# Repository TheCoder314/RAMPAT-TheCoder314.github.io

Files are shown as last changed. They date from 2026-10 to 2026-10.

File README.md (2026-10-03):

# R.A.M.P.A.T.

**Rapid, Affordable, Modular, Printed, Aerial Tiltrotor** — an open-source, 3D-printed tiltrotor VTOL for emergency response, by Aarit Dixit.

Website: `https://thecoder314.github.io/RAMPAT-TheCoder314.github.io/`

## Downloads

| File | Contents |
| --- | --- |
| `files/RAMPAT-all-files.zip` | Everything: STEP, STLs, PCB Gerbers, poster |
| `files/cad/RAMPAT-CAD-assembly-STEP.zip` | Full assembly for modification |
| `files/cad/RAMPAT-printable-STL.zip` | 53 printable parts + parts list |
| `files/pcb/RAMPAT-PCB.zip` | Flight controller Gerbers, upload directly to a fab |

## Printing (LW-PETG, gyroid infill)

| Parts | Walls | Infill |
| --- | --- | --- |
| Fuselage shells | 1 | 3% |
| Wings | 1 | 5% |
| Connectors | 3 | 20% |
| Everything else | 2 | 20% |

## Repo layout

```
index.html              the website
assets/                 images and part thumbnails
files/                  everything visitors download
source/cad/             full STEP assembly + parts-list.csv
source/pcb/             Gerber + drill files from KiCad
tools/build_zips.py     rebuilds every ZIP in files/
```

After changing anything in `source/` or `files/cad/stl/`, run `python3 tools/build_zips.py`.

## Publish on GitHub Pages

1. Push this folder to a GitHub repository.
2. Settings → Pages → Deploy from a branch → `main`, `/ (root)`.

## License

[CC BY-NC 4.0](https://creativecommons.org/licenses/by-nc/4.0/). See `LICENSE.txt`.

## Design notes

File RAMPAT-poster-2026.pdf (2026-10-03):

Year 2: Development of R.A.M.P.A.T.

# (Rapid, Affordable, Modular, Printed, Aerial Tiltrotor) For Emergency Response

# Aarit Dixit

INTRODUCTION | METHODS | STATISTICAL ANALYSIS

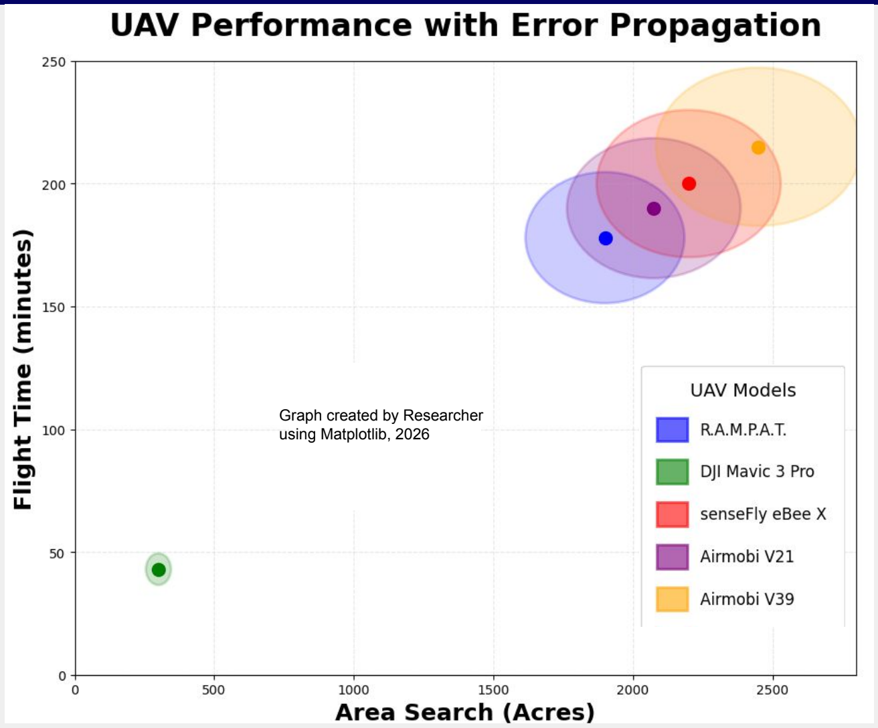
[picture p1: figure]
Graph created by Researcher using Matplotlib, 2026

# CONCLUSIONS

# FUTURE WORK

- First 3D‑printed tiltrotor VTOL for disaster relief delivers $10k‑class endurance and search performance for under $1k, including thermal imaging for full day/night missions.
- Fully modular, 3D‑printed airframe enables fast, low‑cost field repairs and upgrades, turning crashes into quick recoveries and boosting mission flexibility.
- Engineered for resilience with <1% failure risk, trading minor impact‑resistance limits for unmatched maintainability and continuous deployment for fire departments, NGOs, and community teams.

Overall, the engineering design criteria were met based on flight data, validating R.A.M.P.A.T.’s potential as a viable solution for global first responders.

## Unmanned Aerial Vehicles (UAV)

# RESULTS

Fig 1. Airflow Property Fields of R.A.M.P.A.T. Geometry | Fig 2. CFD-Calculated Forces
Low | High

Hovering advantage
Endurance disadvantage

Images of CFD fields, highlighting optimal aerodynamics and airflow separation.

Utility of multirotor,
efficiency of fixed-wing
Expensive (>$12,000)
Extra Weight
Multirotor | Fixed-Wing | VTOL

# DISCUSSION

CFD forces show convergence, highlighting a valid simulation.
Chart created by Researcher using Google Sheets, 2026

Modeling: Using manufacturer data, assorted industry UAVs were compared to R.A.M.P.A.T., with the company-reported data ranges being used for analysis.
Overlap Interpretation: Overlap of uncertainty envelopes indicates plausible performance similarity, while non-overlap suggests likely separation.
Comparative Inference: Within uncertainty bounds, R.A.M.P.A.T. overlaps with mid-tier platforms (~$8-12k) at a cost of less than $1000 and demonstrates clear separation from lower-cost alternatives (4-6x better), showing dominance in cost-constrained regimes.

Graph displays the overlap in area search capability and flight time shown by R.A.M.P.A.T. and industry-level drones, showcasing similar performance at a fraction of the cost.

Wing
Wing split in 6 parts and slotted together with a carbon-fiber tube for rigidity. Uses a NACA 6409 airfoil for high lift and control authority.

Fuselage
Three-part fuselage stores avionics and payload, including battery, PCB, and thermal camera.

Tilt Mechanism
To efficiently switch between flight modes, a tilt mechanism changes the motor angle
based on flight mode.

V-Tail
To reduce drag compared to T-tails, a V-tail combines the pitch and yaw axes in
differential movement.

Cruise/Endurance efficiency Limited take-off versatility

Flight Testing Procedure

Preflight
- Install battery, power avionics, verify telemetry, control surfaces
- Arm system; confirm hover, transition, and fixed-wing modes

Hover Test
- Vertical takeoff in hover
- Hold altitude for 5 minutes, log current draw and
gyroscope data

Fixed-Wing Cruise
- Switch to fixed-wing mode
- Cruise for 10 minutes to log gyroscope, airspeed, and
power use data

Recovery
- Transition back to hover
- Controlled vertical landing
- Disarm and power down
avionics
- Repeat 15 times

Transition Test
- Climb to 50 ft AGL
- Enter transition mode
- Hold fixed throttle for 2 minutes, log gyroscope and airspeed data
- Locate survivors & assess damage to aid first responders in rescue missions
- Able to operate in hostile environments unsuitable for humans.
- Deliver critical supplies to stranded victims ahead of ground teams
- Extremely expensive (>$10,000), keeping them out of reach for over 80% of global first-responder agencies
Background | ➢ In the past decade, over 400,000 lives
| were lost to natural disasters, most of which happened in developing countries. ➢ Of these, a projected 75% of casualties happened in the 48 hours after the event, during which first responders were critical for analyzing damage and rescue missions. ➢ In the aftermath, aerial reconnaissance is crucial for aiding first responders.

An Unmanned Aerial Vehicle (UAV) is any vehicle that doesn’t have a pilot on board and is either remotely piloted or autonomous.

Flight tests come close to the CFD-calculated “maximum” flight time.

Get IMU
Data

Fuse IMU
Data

Get
Desired
Position

PID Control

Control
Mixing

Actuator
Outputs

Vehicle
Response

Design: Low-cost VTOL using foam and cardboard.
Lesson: Fragile, could not achieve stable flight. Required a complete design overhaul. Important as it established a proof-of-concept.

Design Change: Modular,
3D-printed parts.
Problems: Misaligned CoG,
high aerodynamic drag, and structural instability from wooden spars.
Lesson: Core concept was
viable, but the airframe
structure and aerodynamics needed complete revision for flight.
Iteration 1 | Iteration 2 | Iteration 3

Design Changes:
Replaced wooden
spars/booms with carbon fiber for strength, weight, and
correct CoG.
Improved aerodynamics using CFD data and a V-tail design. Implemented a part-slotting system.
Outcome: Achieved structural stability and flight performance.

Aftermath of Hurricane Melissa in Jamaica, 2025. Floods destroyed the country’s ground infrastructure, leading to survivor searching efforts taking nearly two months.
Source: https://supportjamaica.gov.jm/

R.A.M.P.A.T. surpasses its cost category while being comparable to $10,000 systems in the key metrics of endurance and search capability.

UAV in a California forest fire, 2024 Source: www.fire.ca.gov

Due to unique design and cost constraints, a custom flight controller PCB was developed (diagram to the left).

Key features:
- 85% cost reduction ($75 vs. $500+)
- Full sensor integration
- Long-range radio telemetry
- High-frequency flight
stabilization
- Off-the-shelf sensors with custom control software

Flight control loop, controlling stabilization and movement.

R.A.M.P.A.T. has an order-of-magnitude advantage in the metrics of Flight Time Per Dollar and Search Area Per Dollar (Based on retail price of UAVs/material cost of R.A.M.P.A.T, as electrical cost is negligible when environmental factors are taken to consideration)

DJI Mavic, Image from DJI, 2023
https://www.djiusa.com/products/dji-mavic.

SenseFly eBeeX, Image from SenseFly, 2024
https://eaglenxt.com/drones/ebee-x/

Airmobi V21, Image from Airmobi, 2026
https://www.airmobi.com/product/airmobi-v21/
Pressure, 15 m/s | Velocity, 15 m/s
Pressure, 17.5 m/s | Velocity, 17.5 m/s
Pressure, 20 m/s | Velocity, 20 m/s
Pressure, 22.5 m/s | Velocity, 22.5 m/s
Flight Controller | Computational Fluid Dynamics

Full view of PCB, showing signal routes and components.

73% drag
reduction
Geometry 1 | Geometry 7

Geometric Optimization:
- Reducing high-pressure (red) areas.
- Increasing low-pressure (blue) areas on top of the wing.
- These two factors increase Lift/Drag ratio.

Final Results:
- L/D ratio of 12.1 (industry is 10+).
- High lift at lower speeds, increasing payload capacity.
- Streamlined fuselage + Landing gear.

Photo taken by Researcher, 2024

Image created by
Researcher using
Onshape, 2025

Image created by
Researcher using Onshape, 2025

Image created by Researcher using Onshape, 2025

Chart created by Researcher using Google Sheets, 2026

Image created by
Researcher using
SimScale, 2025

Image created by
Researcher using
SimScale, 2025

Image created by
Researcher using
SimScale, 2025

Image created by
Researcher using
SimScale, 2025

Image created by
Researcher using
SimScale, 2025

Image created by
Researcher using
SimScale, 2025

Image created by
Researcher using
SimScale, 2025

Image created by
Researcher using
SimScale, 2025

Image created by Researcher using SimScale, 2025

Image created by Researcher using SimScale, 2025

Diagram created by Researcher using Google Drawing, 2025

Image created by Researcher using KiCad, 2025

Diagram created by Researcher using Google Drawing, 2026

Proportion-Integral-Derivative Equation Transition Control Mixing Equation

where:
- δ is the true control surface output.
- δcmd is the pilot-given control surface output.
- V represents the measured velocity

# RESEARCH OBJECTIVES

Engineering Problem
Current UAVs are not sufficiently accessible to global first responder groups due to a lack of balance between performance and monetary cost.
Research Question
Can we develop a cost-efficient UAV that balances performance and cost to be an effective tool for first responders?

## Engineering Design Criteria

Performance:
>1800 acre search
capability, >2.75
hour endurance

Affordability:
Contain a materials
cost of <$1000

Functionality:
Swappable parts,
VTOL capability

Brainstorming R.A.M.P.A.T.

### 3D Printed Manufacturing

### Tiltrotor Propulsion

### Modular Design

Hover | Transition | Cruise
- Traditional VTOLs use redundant propulsion systems for hover and cruise.
- Tiltrotor VTOLs combine hover and cruise in the same propulsion system, reducing cost.
- While developed, tiltrotor VTOLs are rarely used in first response and have never been implemented in a 3D-printed first response aircraft.
- Parts slot together, allowing for repairs and upgrades.
- Combined with 3D printing, this allows R.A.M.P.A.T. to be easily repaired.
- Total assembly time (including manufacturing+part sourcing) <48 hours, 5x less than industry UAVs.
CAD Model | 3D Print
- PETG (Polyethylene Terephthalate Glycol-modified) enables rapid, low-cost airframe production
- Allows lightweight, strong structures to maximize flight endurance for long-range search.
- UV-resistant & waterproof

Photo taken by Researcher, 2025 Image created by Researcher using Onshape, 2025

Image created by Researcher using Onshape, 2025

Image created by Researcher using Onshape, 2025

Image created by
Researcher using
Onshape, 2025

Image created by
Researcher using
Onshape, 2025

Image created
by Researcher
using Onshape,
2025

## Aerodynamic Modeling & Validation

- CFD solutions converged across all flight regimes, confirming stable, physically valid aerodynamics.
- Lift, drag, and power predictions aligned closely with flight‑test data.
- Cruise endurance measurements fell within CFD‑predicted bounds, validating the modeling approach.

## Performance Comparison

- Commercial UAV benchmarks used manufacturer‑reported ranges due to lack of variance data.
- R.A.M.P.A.T. variance derived from repeated testing, producing tighter uncertainty (12%).
- Performance judged by overlap of uncertainty envelopes, not single values.
- R.A.M.P.A.T. overlaps mid‑tier ($8k–$12k) UAVs in endurance and search capability; clearly outperforms low‑cost multirotors.

## Cost-Normalized Performance

- Delivers order‑of‑magnitude gains in flight time per dollar and search area per dollar.
- Advantages stem from modular 3D‑printed structure, shared hover/cruise propulsion, and low‑cost custom controller.

## System Design and Operational Impact

- Additive manufacturing introduces minor structural tradeoffs but maintains low failure risk (<1%).
- Modular components enable rapid field repairs.
- Establishes a new cost‑performance benchmark for emergency‑response UAVs.
- Expands access for the 80%+ of first‑responder agencies lacking aerial support.

# ETSD011

Mesh Independence Study | Residual Convergence

where:
- u(t) is the actuator output command.
- e(t) is the error.
- Kp, Ki, and Kd are the proportion, integral, and derivative coefficients.

Chart created by Researcher using Google Sheets, 2026

Chart created by Researcher using Google Sheets, 2026

Equation created by Researcher using Overleaf, 2025 | Equation created by Researcher using Overleaf, 2025

Image created by
Researcher using
SimScale, 2025

### Fig 5. R.A.M.P.A.T. Flight Endurance Compared with CFD-calculated

### Flight Time

Chart created by Researcher using Google Sheets, 2026

UAV | Cost-Based Flight Time (Minutes) | Optimal Area Search (Acres) | Cost (USD)
R.A.M.P.A.T. | 178 | 1900 | $978
DJI Mavic 3 Pro | 43 | 300 | $2,500
senseFly eBeeX | 200 | 2200 | $10,000
Airmobi V21 | 190 | 2075 | $10,000
Airmobi V39 | 215 | 2450 | $11,000

Example swarm network, with 6 R.A.M.P.A.T. UAVs connected with each other to scan an area efficiently.

- Real-World Mission Capability
- Advancing System Autonomy
- Increasing Deployment
Scalability
- Further Environmental and Operational Testing

Sample Data Set

microSD Data
Storage

Plotted Cubic Regression

### Fig 3. Data Extraction Process Fig 4. Industry Comparison Table

Photo taken by Researcher, 2025

Image created by Researcher using Google Sheets, 2025

Image created by Researcher using Matplotlib, 2025

Table created by Researcher using Google Sheets, 2026

### Fig 6. R.A.M.P.A.T. Performance vs Industry

### Fig 7. Cost-Normalized Performance of R.A.M.P.A.T. vs Existing UAVs

Chart created by Researcher using Google Sheets, 2026

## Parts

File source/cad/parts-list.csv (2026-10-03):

group | file | description | print_profile | onshape_name | bounding_box_mm | solid_volume_cm3 | qty
fuselage | fuselage/fuselage-center.stl | Center section, wing joint | Fuselage: 1 wall, 3% gyroid | Part 27 | 250 x 150 x 94 | 601.5 | 1
wing | wing/boom-mount-L.stl | Left boom mount, under wing | Connector: 3 walls, 20% gyroid | Part 40 | 42 x 34 x 16 | 11.0 | 1
tail | tail/v-tail-L.stl | Left V-tail surface | Standard: 2 walls, 20% gyroid | Part 85 | 188 x 134 x 71 | 99.6 | 1
wing | wing/aileron-R2.stl | Right control surface, middle | Wing: 1 wall, 5% gyroid | Part 95 | 210 x 50 x 20 | 36.2 | 1
wing | wing/aileron-R3.stl | Right control surface, outboard | Wing: 1 wall, 5% gyroid | Part 94 | 236 x 50 x 20 | 41.3 | 1
wing | wing/wing-root-plate-L.stl | Left wing root plate | Connector: 3 walls, 20% gyroid | Part 30 | 152 x 45 x 5 | 31.9 | 1
wing | wing/wing-panel-R3.stl | Right wing panel | Wing: 1 wall, 5% gyroid | Part 68 | 250 x 114 x 23 | 317.6 | 1
fuselage | fuselage/fuselage-insert.stl | Internal fuselage insert | Standard: 2 walls, 20% gyroid | Part 1 | 134 x 44 x 29 | 169.4 | 1
tail | tail/v-tail-tip-L.stl | Left V-tail tip | Standard: 2 walls, 20% gyroid | Part 86 | 100 x 57 x 44 | 15.0 | 1
tail | tail/ventral-fin.stl | Ventral fin and rear landing leg | Standard: 2 walls, 20% gyroid | Part 47 | 233 x 211 x 38 | 319.7 | 1
wing | wing/wing-panel-L4.stl | Left wing panel, tip | Wing: 1 wall, 5% gyroid | Part 36 | 259 x 170 x 61 | 461.0 | 1
tail | tail/ruddervator-R.stl | Right ruddervator | Standard: 2 walls, 20% gyroid | Part 92 | 149 x 107 x 31 | 16.1 | 1
wing | wing/wing-panel-R1.stl | Right wing panel, root | Wing: 1 wall, 5% gyroid | Part 61 | 252 x 151 x 31 | 359.9 | 1
nacelles | nacelles/boom-fairing-R.stl | Right boom fairing | Standard: 2 walls, 20% gyroid | Part 60 | 157 x 56 x 37 | 83.7 | 1
nacelles | nacelles/servo-frame-L.stl | Left tilt-servo frame | Standard: 2 walls, 20% gyroid | Part 50 | 56 x 29 x 4 | 2.5 | 1
tail | tail/pin-a.stl | Small pin | Connector: 3 walls, 20% gyroid | Part 3 | 6 x 5 x 5 | 0.1 | 1
nacelles | nacelles/tilt-bracket-R-b.stl | Right tilt bracket, servo side | Standard: 2 walls, 20% gyroid | Part 65 | 73 x 45 x 41 | 26.3 | 1
nacelles | nacelles/front-boom-R.stl | Right motor boom with landing leg | Standard: 2 walls, 20% gyroid | Part 66 | 235 x 235 x 44 | 204.3 | 1
wing | wing/aileron-L3.stl | Left control surface, outboard | Wing: 1 wall, 5% gyroid | Part 97 | 236 x 50 x 20 | 41.3 | 1
nacelles | nacelles/servo-frame-R.stl | Right tilt-servo frame | Standard: 2 walls, 20% gyroid | Part 63 | 56 x 29 x 4 | 2.5 | 1
wing | wing/aileron-L1.stl | Left control surface, inboard | Wing: 1 wall, 5% gyroid | Part 96 | 200 x 50 x 20 | 35.8 | 1
nacelles | nacelles/tilt-bracket-R-a.stl | Right tilt bracket | Standard: 2 walls, 20% gyroid | Part 64 | 73 x 45 x 29 | 22.6 | 1
fuselage | fuselage/fuselage-front.stl | Front fuselage section | Fuselage: 1 wall, 3% gyroid | Part 29 | 250 x 150 x 69 | 539.3 | 1
nacelles | nacelles/front-boom-L.stl | Left motor boom with landing leg | Standard: 2 walls, 20% gyroid | Part 71 | 235 x 207 x 35 | 175.8 | 1
nacelles | nacelles/servo-housing-L.stl | Left tilt-servo housing | Standard: 2 walls, 20% gyroid | Part 72 | 56 x 37 x 29 | 33.8 | 1
wing | wing/wing-panel-R4.stl | Right wing panel, tip | Wing: 1 wall, 5% gyroid | Part 59 | 259 x 170 x 61 | 461.0 | 1
tail | tail/tail-mount.stl | Tail mount and rear motor pod | Standard: 2 walls, 20% gyroid | Part 87 | 212 x 93 x 71 | 300.4 | 1
wing | wing/wing-panel-L1.stl | Left wing panel, root | Wing: 1 wall, 5% gyroid | Part 38 | 252 x 151 x 31 | 359.9 | 1
fuselage | fuselage/nose-cone.stl | Streamlined nose cone | Fuselage: 1 wall, 3% gyroid | Part 69 | 178 x 75 x 69 | 411.2 | 1
tail | tail/tail-boom-sleeve-2.stl | Tail boom sleeve, middle | Standard: 2 walls, 20% gyroid | Part 81 | 243 x 38 x 38 | 162.4 | 1
wing | wing/wing-panel-L2.stl | Left wing panel | Wing: 1 wall, 5% gyroid | Part 53 | 155 x 114 x 23 | 180.5 | 1
nacelles | nacelles/tilt-bracket-L-a.stl | Left tilt bracket | Standard: 2 walls, 20% gyroid | Part 51 | 73 x 45 x 29 | 22.6 | 1
wing | wing/aileron-L2.stl | Left control surface, middle | Wing: 1 wall, 5% gyroid | Part 98 | 210 x 50 x 20 | 36.2 | 1
tail | tail/tail-boom-sleeve-3.stl | Tail boom sleeve, rear | Standard: 2 walls, 20% gyroid | Part 82 | 257 x 38 x 38 | 173.8 | 1
wing | wing/wing-panel-R2.stl | Right wing panel | Wing: 1 wall, 5% gyroid | Part 67 | 155 x 114 x 23 | 180.5 | 1
tail | tail/tail-boom-sleeve-1.stl | Tail boom sleeve, front | Standard: 2 walls, 20% gyroid | Part 41 | 233 x 38 x 38 | 147.1 | 1
nacelles | nacelles/tilt-bracket-L-b.stl | Left tilt bracket, servo side | Standard: 2 walls, 20% gyroid | Part 52 | 73 x 45 x 41 | 26.3 | 1
wing | wing/aileron-R1.stl | Right control surface, inboard | Wing: 1 wall, 5% gyroid | Part 93 | 200 x 50 x 20 | 35.8 | 1
fuselage | fuselage/avionics-tray.stl | Floor plate for PCB and battery | Standard: 2 walls, 20% gyroid | Part 70 | 177 x 139 x 3 | 40.4 | 1
tail | tail/v-tail-R.stl | Right V-tail surface | Standard: 2 walls, 20% gyroid | Part 89 | 188 x 134 x 70 | 99.6 | 1
tail | tail/v-tail-tip-R.stl | Right V-tail tip | Standard: 2 walls, 20% gyroid | Part 90 | 100 x 57 x 44 | 15.0 | 1
tail | tail/control-horn-b.stl | Ruddervator control horn | Standard: 2 walls, 20% gyroid | Part 84 | 20 x 7 x 7 | 0.5 | 1
nacelles | nacelles/boom-fairing-L.stl | Left boom fairing | Standard: 2 walls, 20% gyroid | Part 37 | 157 x 56 x 37 | 83.7 | 1
tail | tail/pin-b.stl | Small pin | Connector: 3 walls, 20% gyroid | Part 4 | 6 x 5 x 5 | 0.1 | 1
tail | tail/ruddervator-L.stl | Left ruddervator | Standard: 2 walls, 20% gyroid | Part 91 | 149 x 107 x 31 | 16.1 | 1
tail | tail/control-horn-a.stl | Ruddervator control horn | Standard: 2 walls, 20% gyroid | Part 83 | 10 x 7 x 6 | 0.2 | 1
fuselage | fuselage/tail-boom-joiner.stl | Joins tail boom to center section | Connector: 3 walls, 20% gyroid | Part 88 | 65 x 27 x 27 | 37.2 | 1
wing | wing/wing-root-plate-R.stl | Right wing root plate | Connector: 3 walls, 20% gyroid | Part 31 | 152 x 45 x 5 | 32.0 | 1
tail | tail/rear-tilt-bracket-b.stl | Rear motor tilt bracket, servo side | Standard: 2 walls, 20% gyroid | Part 80 | 73 x 45 x 41 | 26.3 | 1
tail | tail/rear-tilt-bracket-a.stl | Rear motor tilt bracket | Standard: 2 walls, 20% gyroid | Part 79 | 73 x 45 x 29 | 22.6 | 1
wing | wing/wing-panel-L3.stl | Left wing panel | Wing: 1 wall, 5% gyroid | Part 54 | 250 x 114 x 23 | 317.6 | 1
wing | wing/boom-mount-R.stl | Right boom mount, under wing | Connector: 3 walls, 20% gyroid | Part 100 | 42 x 34 x 16 | 11.0 | 1
tail | tail/rear-servo-frame.stl | Rear tilt-servo frame | Standard: 2 walls, 20% gyroid | Part 78 | 56 x 29 x 4 | 2.5 | 1

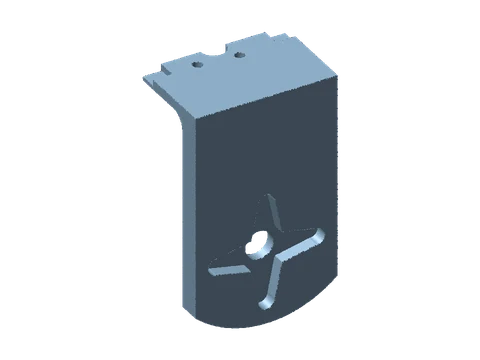
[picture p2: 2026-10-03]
assets/parts/tilt-bracket-L-a.webp

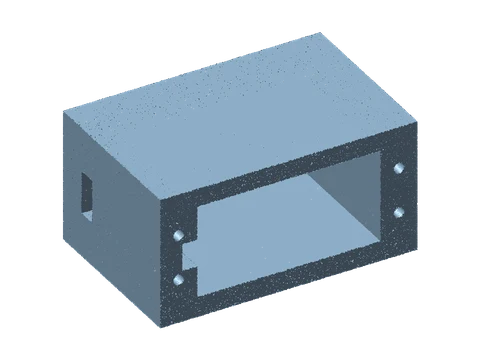
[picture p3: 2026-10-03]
assets/parts/servo-housing-L.webp

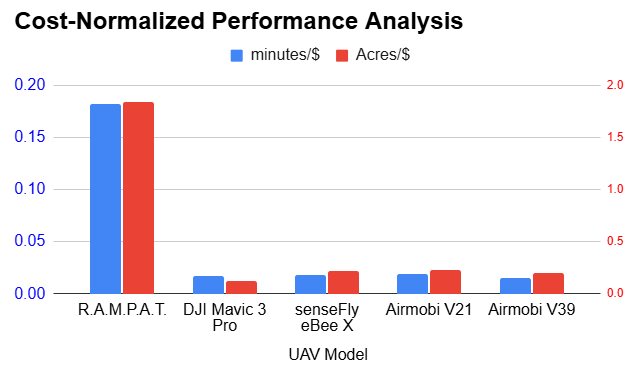
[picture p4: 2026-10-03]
assets/img/cost-normalized.jpg

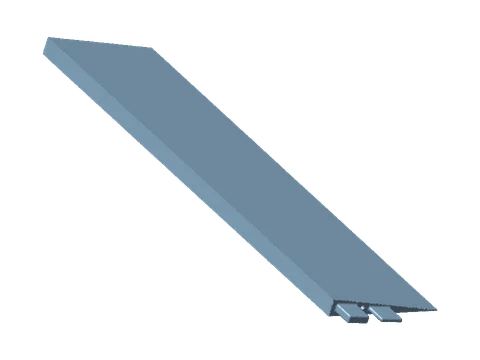
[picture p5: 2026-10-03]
assets/parts/aileron-R3.webp

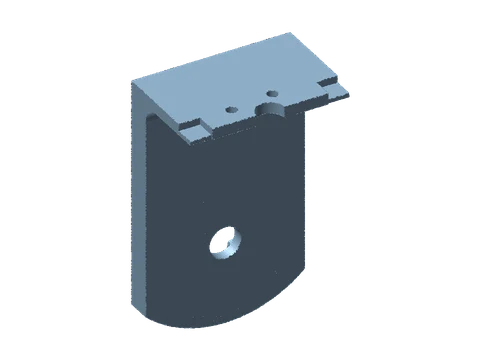
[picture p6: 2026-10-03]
assets/parts/tilt-bracket-R-a.webp

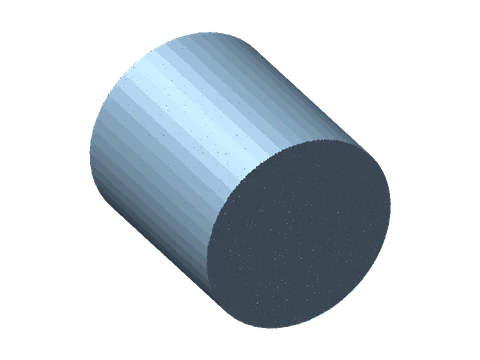
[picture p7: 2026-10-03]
assets/parts/pin-a.webp

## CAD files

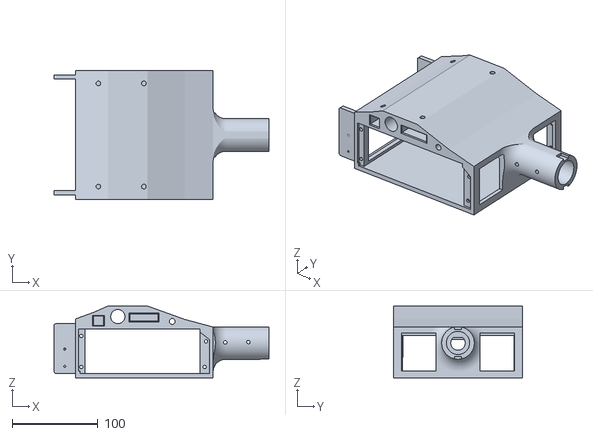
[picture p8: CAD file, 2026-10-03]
files/cad/stl/fuselage/fuselage-center.stl
250.2 x 150.0 x 83.7

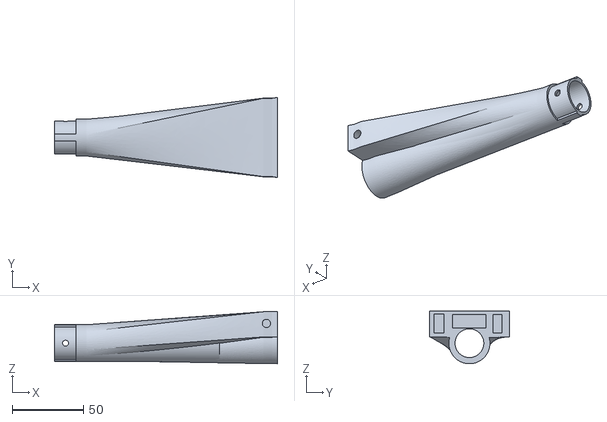
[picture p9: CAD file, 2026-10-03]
files/cad/stl/nacelles/boom-fairing-L.stl
157.0 x 56.4 x 37.0

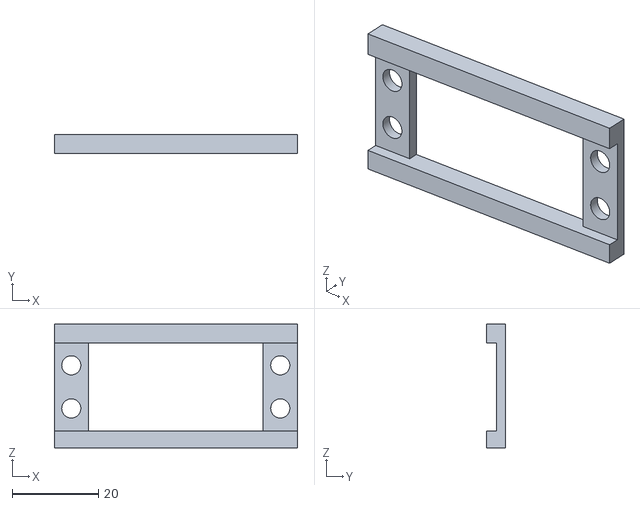
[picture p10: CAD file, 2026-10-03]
files/cad/stl/tail/rear-servo-frame.stl
56.4 x 4.30 x 28.7

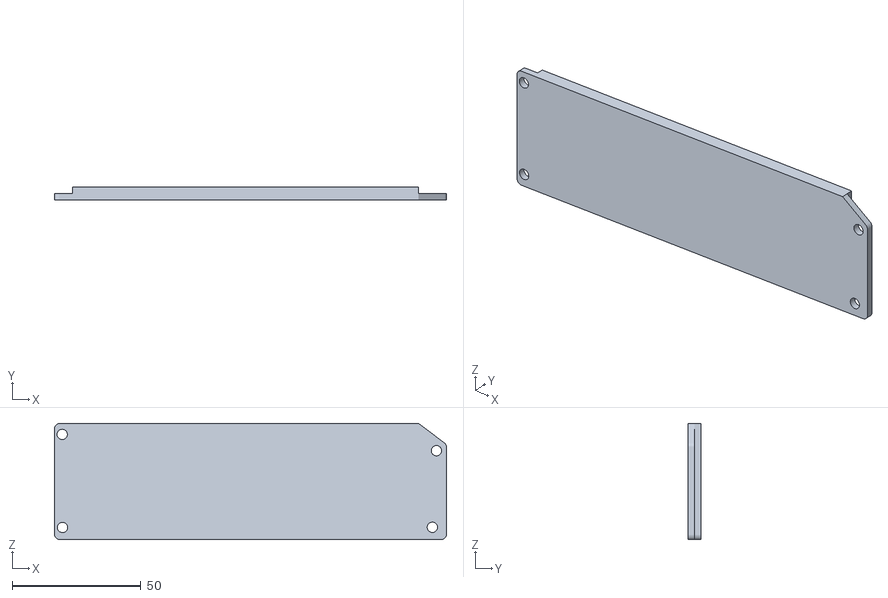
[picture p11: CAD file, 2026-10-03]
files/cad/stl/wing/wing-root-plate-L.stl
152.0 x 5.00 x 45.0

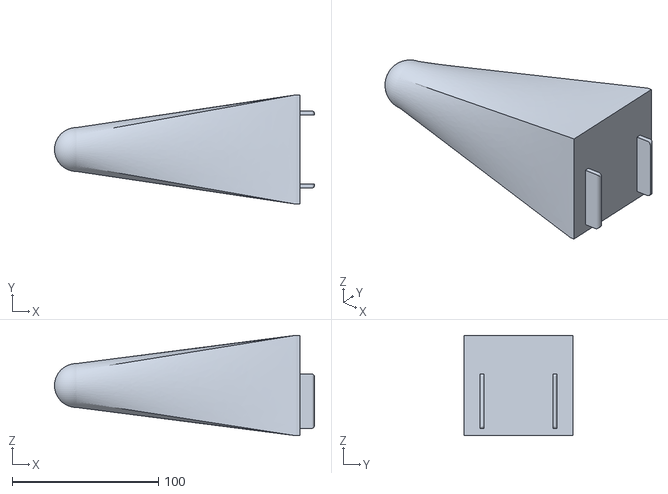
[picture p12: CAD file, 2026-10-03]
files/cad/stl/fuselage/nose-cone.stl
177.6 x 74.7 x 68.6

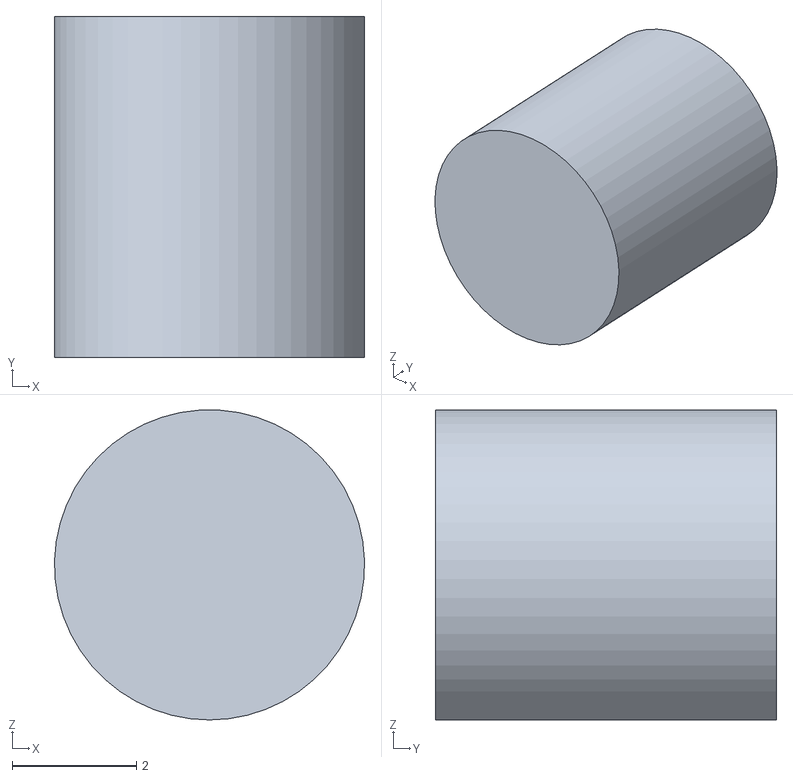
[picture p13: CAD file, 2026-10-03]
files/cad/stl/tail/pin-a.stl
5.00 x 5.50 x 5.00

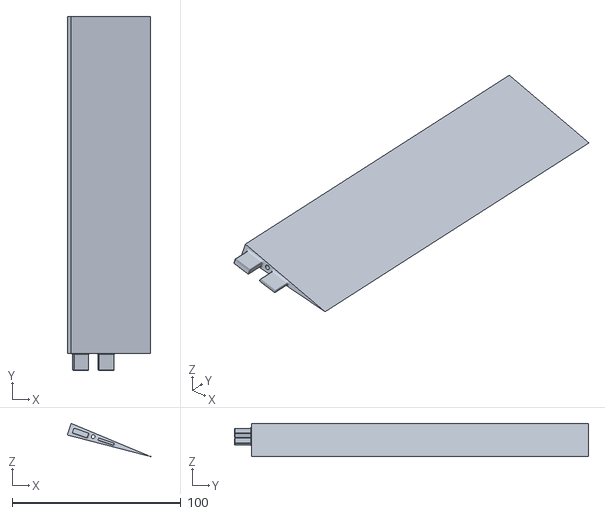
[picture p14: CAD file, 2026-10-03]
files/cad/stl/wing/aileron-R2.stl
49.5 x 210.0 x 19.7

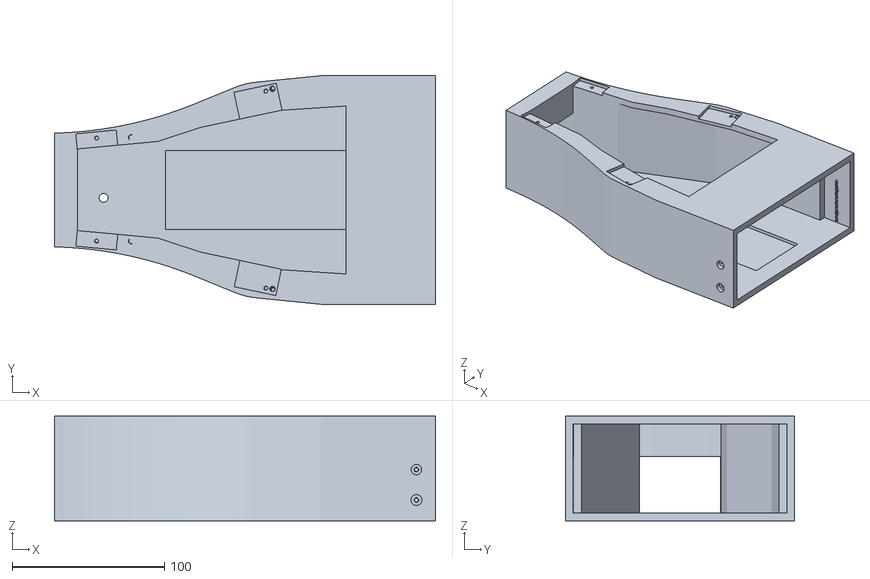
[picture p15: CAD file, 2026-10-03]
files/cad/stl/fuselage/fuselage-front.stl
250.0 x 150.0 x 68.6

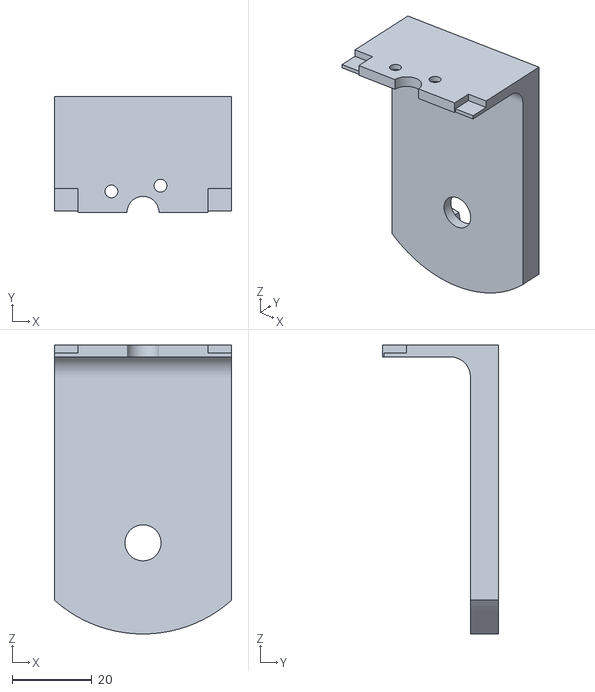
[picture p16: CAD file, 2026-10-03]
files/cad/stl/nacelles/tilt-bracket-R-a.stl
44.6 x 29.0 x 72.6

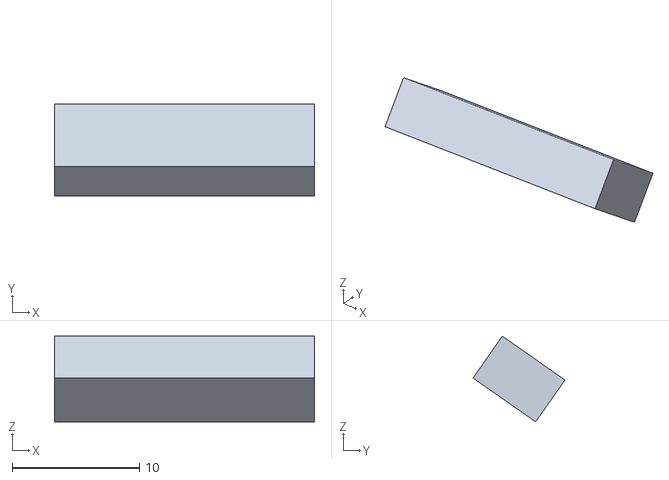
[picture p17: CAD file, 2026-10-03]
files/cad/stl/tail/control-horn-b.stl
20.4 x 7.22 x 6.73

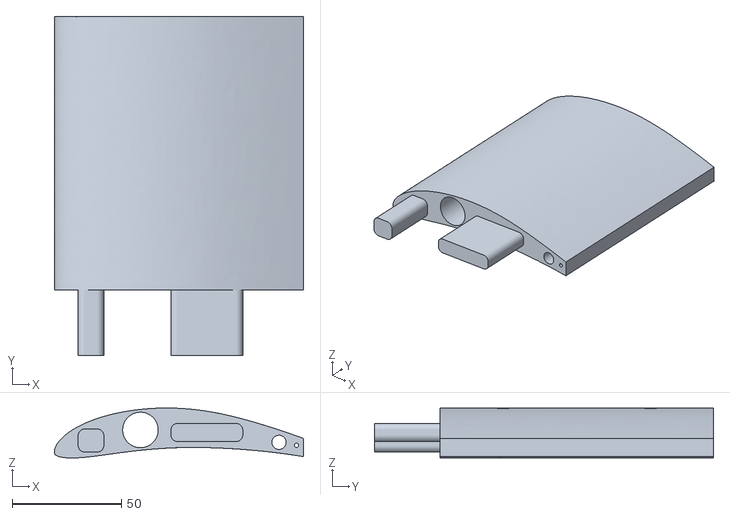
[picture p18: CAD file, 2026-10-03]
files/cad/stl/wing/wing-panel-R2.stl
114.0 x 155.0 x 22.9

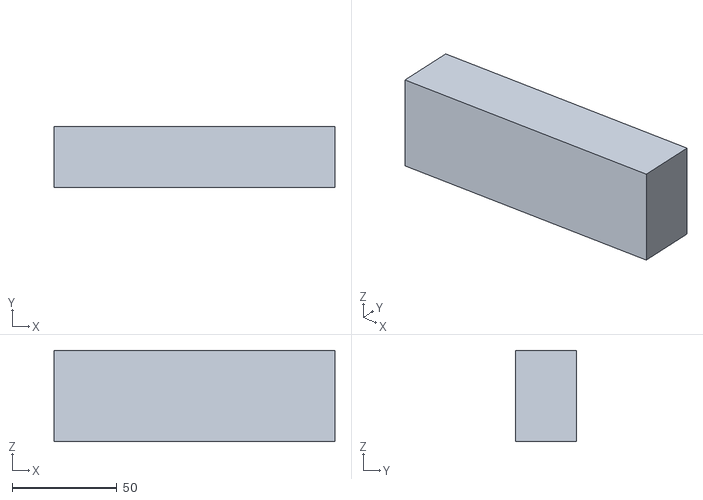
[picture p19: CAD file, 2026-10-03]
files/cad/stl/fuselage/fuselage-insert.stl
134.3 x 29.0 x 43.5

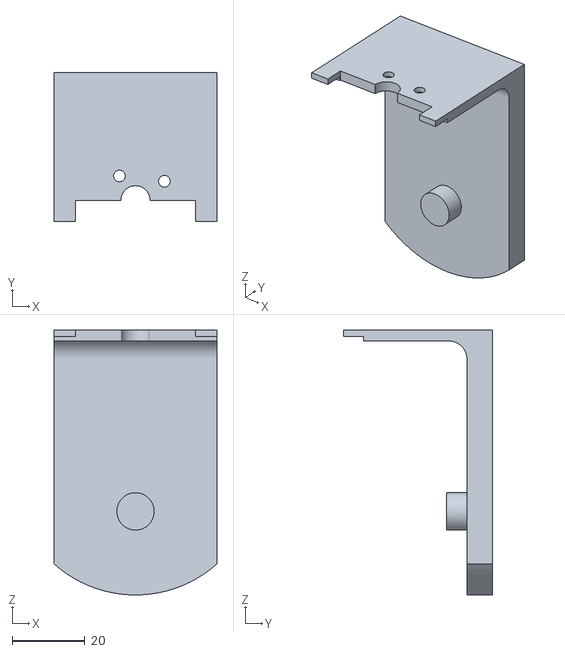
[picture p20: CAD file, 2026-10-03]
files/cad/stl/nacelles/tilt-bracket-L-b.stl
44.6 x 40.8 x 72.6

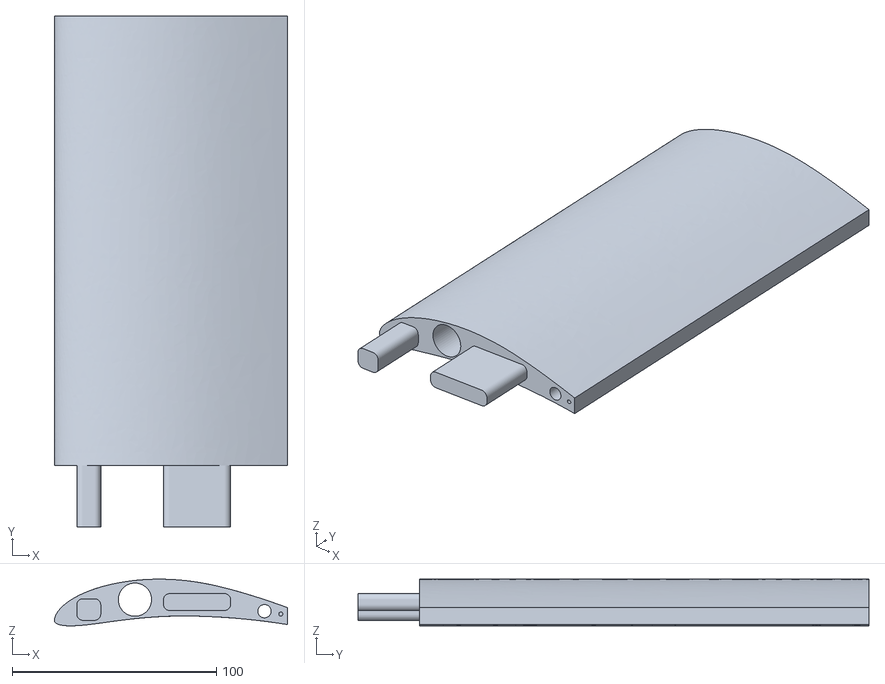
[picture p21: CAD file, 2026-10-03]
files/cad/stl/wing/wing-panel-R3.stl
114.0 x 250.0 x 22.9

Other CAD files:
files/cad/stl/nacelles/boom-fairing-R.stl
files/cad/stl/tail/pin-b.stl
files/cad/stl/fuselage/avionics-tray.stl
files/cad/stl/nacelles/tilt-bracket-R-b.stl
files/cad/stl/fuselage/tail-boom-joiner.stl
files/cad/stl/nacelles/front-boom-L.stl
files/cad/stl/nacelles/front-boom-R.stl
files/cad/stl/nacelles/servo-frame-L.stl
files/cad/stl/nacelles/servo-frame-R.stl
files/cad/stl/nacelles/servo-housing-L.stl
files/cad/stl/nacelles/tilt-bracket-L-a.stl
files/cad/stl/tail/control-horn-a.stl
files/cad/stl/tail/rear-tilt-bracket-a.stl
files/cad/stl/tail/rear-tilt-bracket-b.stl
files/cad/stl/tail/ruddervator-L.stl
files/cad/stl/tail/ruddervator-R.stl
files/cad/stl/tail/tail-boom-sleeve-1.stl
files/cad/stl/tail/tail-boom-sleeve-2.stl
files/cad/stl/tail/tail-boom-sleeve-3.stl
files/cad/stl/tail/tail-mount.stl
files/cad/stl/tail/v-tail-L.stl
files/cad/stl/tail/v-tail-R.stl
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

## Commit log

2026-10-03 3D part carousel, fix part search and filters, new poster
2026-10-03 Part pop-up with 3D model, print settings and weight estimates
